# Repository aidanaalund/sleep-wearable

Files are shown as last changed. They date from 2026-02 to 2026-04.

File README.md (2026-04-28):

# UT Austin ECE Senior Design Project: Sleep Monitoring Headband

## Description

This repository contains work on our sleep state tracker wearable headband for ECE Senior Design at UT Austin. Members are Aidan Aalund, Justin Banh, Alex Ho, and Kien Ton. Mentored by Dr. Edison Thomaz. The wearable is powered by a Nordic nRF54L15 module and uses an ADS1299 biosensing amplifier from Texas Instruments for the analog front end. Bluetooth low energy transmits EEG and motion features collected by the board to a mobile app, which runs a random forest model to identify the user's current sleep stage. The app shows trends over time, ratings of sleep quality, and gives tips for improvements.

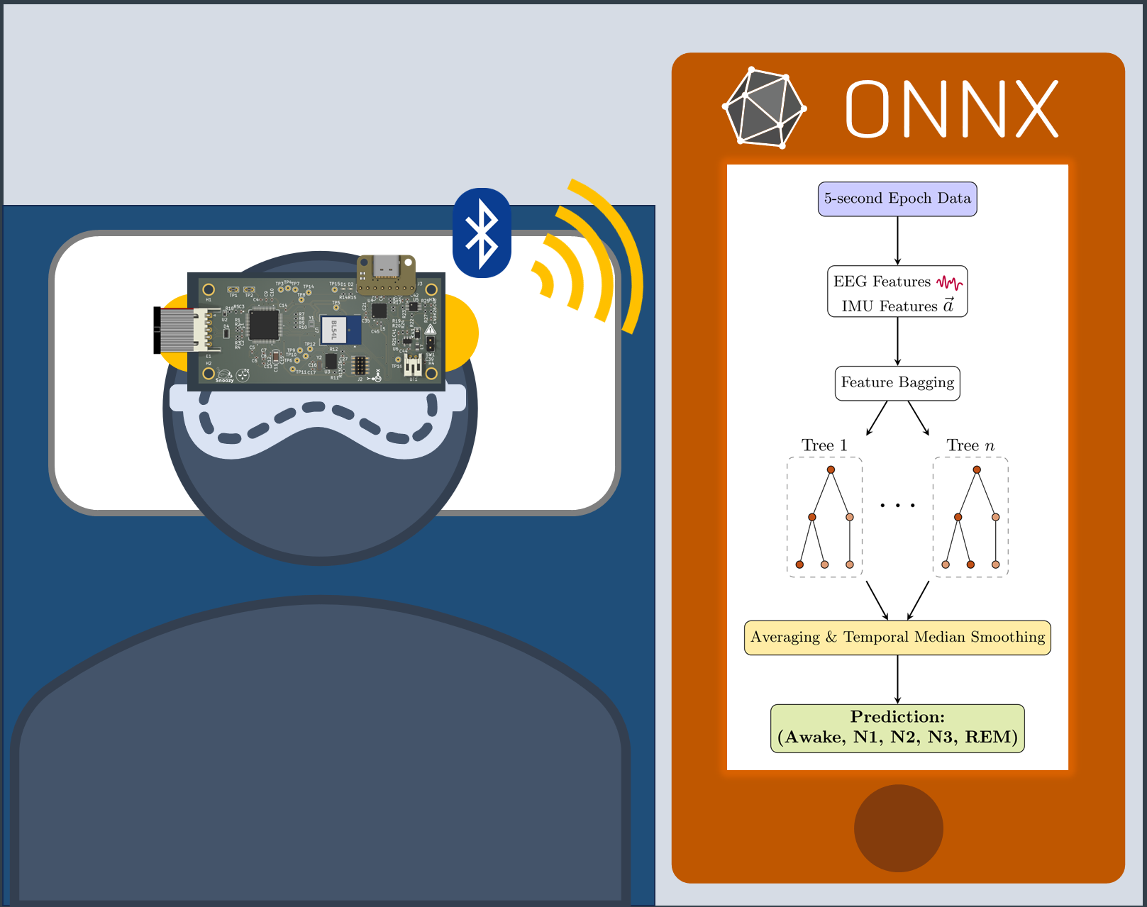
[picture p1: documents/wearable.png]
3D model of hardware showing a PCB and battery.

To view the full PCB layout online, [go to KiCanvas!](https://kicanvas.org/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)

## Repository Structure (WIP)

### Wearable device files (`./wearable`)

#### Hardware Files (`./wearable/hw`)

#### Software Files (`./wearable/sw`)

### Companion application files (`./reactNative`)

### Machine learning files (`./ml`)

#### Sleep Stage Classifier (`./ml/sleep`)

#### Meditation Classifier (`./ml/meditation`)

### Other documentation (`./documents`)

## Known Errata

- SWCLK and SWDIO labels are connected to the SWD header incorrectly in the schematic and layout

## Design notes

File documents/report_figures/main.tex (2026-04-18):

\documentclass[tikz, border=10pt]{standalone}
\usepackage[dvipsnames]{xcolor}
\usepackage{pgfplots}
\pgfplotsset{compat=1.18}
\usetikzlibrary{calc,positioning,arrows.meta}

\tikzset{
  black arrow/.style={-stealth, thick},
  node box/.style={draw=black, fill=white, text=black, rectangle, rounded corners, font=\small, align=center, minimum height=2em},
  % FIXED: Manual path for stability. No sin/cos calculations to crash the engine.
  eeg wave/.pic={
    \draw[purple, thick, x=0.05cm, y=0.15cm] 
      (0,0) -- (1,1) -- (2,-1) -- (3,1.5) -- (4,-1.2) -- (5,0.8) -- 
      (6,-0.5) -- (7,1.2) -- (8,-1.5) -- (9,0.5) -- (10,0);
  }
}

\begin{document}
\begin{tikzpicture}[font=\sffamily]

  % --- ROOT DATA INPUT ---
  \node[node box, fill=blue!20] (root) {5-second Epoch Data};

  % --- EEG BRANCH ---
  \node[node box, below=1cm of root] (eeg_input) {
    EEG Features \tikz[baseline=-0.5ex]{\pic {eeg wave}}\\
    IMU Features \large $\vec{a}$
  };
  
  \node[node box, below=1cm of eeg_input] (eeg_bagging) {Feature Bagging};
  
  % EEG Forest Representative Trees (placed as images)
  \node[inner sep=0pt] at ($(eeg_bagging)+(-1.5cm,-2.5cm)$) (et1) {};
  \node[inner sep=0pt] at ($(eeg_bagging)+(1.5cm,-2.5cm)$) (etn) {};

  \node[node box, below=4.5cm of eeg_bagging, fill=Goldenrod!50] (eeg_avg) {Averaging \& Temporal Median Smoothing};
  \node[node box, fill=SpringGreen!50, below=1cm of eeg_avg, font=\bfseries] (eeg_pred) {Prediction:\\(Awake, N1, N2, N3, REM)};

  % --- OVERRIDE LOGIC ---
  % \node[node box, fill=Goldenrod!50, below=1cm of eeg_pred.south, minimum width=4cm] (logic) {
  %   Override Logic:\\
  %   \textbf{IF} EEG = N1 \textbf{AND} IMU = Awake\\
  %   \textbf{THEN} Final = Awake
  % };

  % --- CONNECTIONS ---
  \draw[black arrow] (root) -- (eeg_input);
  
  \draw[black arrow] (eeg_input) -- (eeg_bagging);
  \draw[black arrow] (eeg_bagging) -- (et1);
  \draw[black arrow] (eeg_bagging) -- (etn);
  \draw[black arrow] (et1) -- (eeg_avg);
  \draw[black arrow] (etn) -- (eeg_avg);
  \draw[black arrow] (eeg_avg) -- (eeg_pred);

  % Ellipsis for forests
  \path (et1) -- (etn) node [midway, scale=2] {$\dots$};
  % \path (it1) -- (itn) node [midway, scale=2] {$\dots$};

\end{tikzpicture}
\end{document}

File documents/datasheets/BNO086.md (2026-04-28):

# BNO08X (BNO085/BNO086) Datasheet — Driver Reference

> Condensed from CEVA BNO08X Datasheet Revision 1.17 (2023). Optimized for writing
> Zephyr RTOS drivers. Detailed electrical/AC timing curves and packaging info have
> been summarized; protocol, report, and command details are preserved in full.

## 1. Overview

The BNO08X is a System in Package (SiP) integrating:

- Triaxial 12-bit accelerometer, range ±8g
- Triaxial 16-bit gyroscope, range ±2000°/s
- Triaxial geomagnetic sensor (magnetometer)
- 32-bit ARM Cortex-M0+ microcontroller running CEVA's SH-2 firmware (with MotionEngine)
- 28-pin LGA package, 3.8 × 5.2 × 1.1 mm

Sensors are from Bosch Sensortec; the MCU is by Atmel. The BNO086 is a drop-in
replacement for the BNO085 (identical pinout and software feature set), and adds
14-bit accelerometer fusion, lower idle power, and Interactive Calibration.

The chip provides processed motion outputs (orientation quaternions, linear accel,
gravity, calibrated gyro/mag, etc.), classification features (step counter, tap,
stability, shake, significant motion, activity), and supports environmental sensors
on a secondary I²C bus.

Host communication interfaces: **I²C, UART (SHTP), SPI, UART-RVC**, plus a bootloader
for DFU.

---

## 2. Pinout (28-pin LGA)

| Pin | Name | Mode | Description |
|-----|---|---|---|
| 1 | RESV_NC | NC | Reserved, no connect |
| 2 | GND | Input | Ground |
| 3 | VDD | Input | Sensor supply (2.4 V – 3.6 V) |
| 4 | BOOTN | Input | Bootloader mode select (low at reset → bootloader) |
| 5 | PS1 | Input | Protocol select pin 1 |
| 6 | PS0/WAKE | Input | Protocol select pin 0; doubles as SPI WAKE after reset |
| 7 | RESV_NC | Input | Reserved, no connect |
| 8 | RESV_NC | NC | Reserved, no connect |
| 9 | CAP | — | External 100 nF cap to GND |
| 10 | CLKSEL0 | Input | Clock source selection (internal pulldown) |
| 11 | NRST | Input | Active-low reset |
| 12 | RESV_NC | NC | Reserved, no connect |
| 13 | RESV_NC | NC | Reserved, no connect |
| 14 | H_INTN | Output | Active-low interrupt to host |
| 15 | ENV_SCL | Bidir | Environmental sensor I²C clock |
| 16 | ENV_SDA | Bidir | Environmental sensor I²C data |
| 17 | SA0 / H_MOSI | Input | I²C address LSB / SPI MOSI |
| 18 | H_CSN | Input | SPI chip select, active low |
| 19 | H_SCL / SCK / RX | Bidir | I²C clock / SPI clock / UART RX |
| 20 | H_SDA / H_MISO / TX | Bidir | I²C data / SPI MISO / UART TX |
| 21–24 | RESV_NC | NC | Reserved, no connect |
| 25 | GND | Input | Ground |
| 26 | XOUT32 / CLKSEL1 | Output | 32 kHz crystal output / clock-source select (pulldown) |
| 27 | XIN32 | Input | 32 kHz crystal input / external clock |
| 28 | VDDIO | Input | Core/IO supply (1.65 V – 3.6 V) |

### 2.1 Clock Source Selection

| Source | CLKSEL0 | CLKSEL1 |
|---|---|---|
| Crystal (32.768 kHz, 50 ppm, 12.5 pF) | 0 / NC | Tied to crystal |
| External clock (50 ppm) | 1 | 1 |
| Internal | 1 | 0 / NC |

> **Important:** the internal clock is **not accurate enough** for UART-SHTP or
> UART-RVC. Use external clock or crystal for UART modes.

---

## 3. Protocol Selection

The PS1/PS0 pins (sampled at reset) and BOOTN pin choose the host interface:

| PS1 | PS0 | BNO08X (BOOTN=1) | Bootloader (BOOTN=0) |
|-----|-----|---|---|
| 0 | 0 | I²C | I²C |
| 0 | 1 | UART-RVC | Reserved |
| 1 | 0 | UART-SHTP | UART |
| 1 | 1 | SPI | SPI |

In **SPI mode**, PS0 is repurposed as the WAKE signal *after* reset.

---

## 4. Host Interfaces

### 4.1 I²C

- Standard Fast-mode, up to **400 kbps**
- 7-bit slave address: `0b1001010X` where X = SA0 pin
  - SA0 = 0 → `0x4A`; SA0 = 1 → `0x4B`
- Bootloader I²C address: `0x28` or `0x29` (SA0 LSB)
- Master MUST support **clock stretching**
- Multi-byte data is **little-endian**, byte transfers are MSB-first
- Repeated-start register-style accesses are **not** supported by the application
  (uses SHTP framing, see §5)
- BNO085 polling with no data → device stretches clock until data is available
- BNO086 polling with no data → device returns zero-length packet; host should
  read the length field and **ignore zero-length packets**

#### Connection guidelines
- `H_INTN` (active low) → GPIO with wake capability
- `BOOTN` → 10 kΩ pull-up; tie to GPIO if DFU is needed
- `PS1`, `PS0` → both tied to GND for I²C
- `H_SCL`/`H_SDA` need pull-ups (~2–4 kΩ depending on bus capacitance)
- Secondary `ENV_SCL`/`ENV_SDA` lines must be pulled up regardless of presence of
  environmental sensors (firmware probes them at reset)

### 4.2 UART-SHTP

- 3 Mbps, 8N1, no parity, idle high
- LSB first
- Bytes from host → BNO must be separated by **≥ 100 µs**
- Bytes from BNO → host have no extra spacing
- `H_INTN` is asserted low ~7.7 µs before the first byte of a transmission and
  deasserts before the last byte; used for host-side timestamping
- Requires external clock or crystal
- Pin tying: PS1 = VDDIO, PS0 = GND
- Uses SHTP framing (see §5) with start/end framing bytes

### 4.3 SPI

- 4-wire, mode 3 (CPOL = 1, CPHA = 1; clock idles high, sampled on rising edge)
- Up to 3 MHz
- MSB first, 8-bit byte oriented
- BNO08X is always slave
- `H_INTN` indicates the BNO has data ready or has woken up
- Pin tying: PS1 = VDDIO, PS0 = GPIO (used as WAKE *after* reset)

#### Wake operation
1. Host drives PS0/WAKE low
2. BNO asserts `H_INTN` low
3. Host asserts `H_CSN` and reads/writes
4. BNO deasserts `H_INTN` once `H_CSN` is observed

#### Responding to H_INTN
If the host fails to respond to `H_INTN` within ~10 ms, the BNO times out,
deasserts `H_INTN`, and retries. Repeated delays cause processing starvation
and degraded outputs. **Target: handle `H_INTN` within 1/10 of the fastest
configured sensor period.**

### 4.4 UART-RVC

- 115200 bps, 8N1, no parity, idle high
- One-way, 100 Hz, fixed 19-byte packets transmitted by BNO
- Requires external clock or crystal
- Pin tying: PS1 = GND, PS0 = VDDIO

#### RVC Packet Format (19 bytes)

| Offset | Field | Notes |
|---|---|---|
| 0–1 | Header | `0xAA 0xAA` |
| 2 | Index | Monotonic 8-bit counter |
| 3–4 | Yaw | int16 LE, 0.01° units, ±180° around Z |
| 5–6 | Pitch | int16 LE, 0.01° units, ±90° around Y |
| 7–8 | Roll | int16 LE, 0.01° units, ±180° around X |
| 9–10 | X accel | int16 LE, mg |
| 11–12 | Y accel | int16 LE, mg |
| 13–14 | Z accel | int16 LE, mg |
| 15 | MI | BNO086: Motion Intent. Otherwise reserved |
| 16 | MR | BNO086: Motion Request. Otherwise reserved |
| 17 | Reserved | One byte (BNO086) or three (otherwise), zero |
| 18 | Csum | Sum of bytes 2–17 (Index, yaw, pitch, roll, accel, reserved) |

Apply rotations in order **yaw → pitch → roll** to recover orientation.

Example (from datasheet):
`AA AA DE 01 00 92 FF 25 08 8D FE EC FF D1 03 00 00 00 E7`
- Index = 0xDE = 222
- Yaw = 0x0001 → 0.01°
- Pitch = 0xFF92 → −1.10°
- Roll = 0x0825 → 20.85°
- X = 0xFE8D → −371 mg
- Y = 0xFFEC → −20 mg
- Z = 0x03D1 → 977 mg
- Csum = 0xE7

#### RVC startup banner
On reset, the BNO transmits an ASCII banner, e.g.:
```
%Hillcrest Labs 10003608
%SW Ver 3.2.x
%(c) 2017 Hillcrest Laboratories, Inc.
```
Then 100 Hz packets stream continuously.

---

## 5. SHTP (Sensor Hub Transport Protocol)

Used by I²C, UART-SHTP, and SPI. Every transfer begins with a 4-byte header:

| Byte | Field |
|---|---|
| 0 | Length LSB |
| 1 | Length MSB (bit 15 = continuation flag) |
| 2 | Channel |
| 3 | SeqNum |

- **Length:** total bytes including header. Bit 15 of MSB byte = continuation
  flag (host shouldn't send fragmented messages to the BNO; the BNO can send
  them). Length `0xFFFF` is reserved (failure marker). Max cargo = 32766 − 4.
- **Channel:** SHTP channel number (see below)
- **SeqNum:** monotonic per-channel-per-direction counter (used to detect drops
  and pair fragments)

The length field allows hosts to schedule the right number of clocks for I²C/SPI
reads. Partial reads are supported — read 4 bytes to get the length, then re-read
with the right size.

### 5.1 SHTP Channels

| Ch | Name | Purpose |
|----|---|---|
| 0 | Command | SHTP control |
| 1 | Executable | Reset / on / sleep commands |
| 2 | SH-2 control | Sensor hub config and responses |
| 3 | Input reports | Non-wake sensor reports (excluding gyro RV) |
| 4 | Wake input reports | Reports from sensors flagged as wake |
| 5 | Gyro RV | Gyro Rotation Vector (separate channel for low latency) |

### 5.2 Executable Channel (Channel 1)

| Direction | Value | Meaning |
|---|---|---|
| Host → BNO | 0 | Reserved |
| Host → BNO | 1 | Reset |
| Host → BNO | 2 | On (re-enable all sensors) |
| Host → BNO | 3 | Sleep (only wake/always-on sensors keep running) |
| BNO → Host | 1 | Reset complete |

### 5.3 Reset Sequence

After power-on or NRST:
1. BNO asserts `H_INTN` when ready
2. Host reads the **SHTP advertisement packet** (channel maps, packet length info)
3. Executable channel sends a reset message
4. SH-2 sends an unsolicited initialization message on channel 2
5. BNO waits for host configuration

Startup timing (typ): NRST pulse ≥ 10 ns, internal init ≈ 90 ms, internal
config ≈ 4 ms before `H_INTN` first asserts.

---

## 6. SH-2 Report IDs (Channel 2 — Sensor Hub Control)

All commands/responses on channel 2 begin with a Report ID (after the SHTP header):

| Report ID | Direction | Description |
|---|---|---|
| 0xFE | Host → BNO | Get Feature Request |
| 0xFD | Host → BNO | Set Feature Command |
| 0xFC | BNO → Host | Get Feature Response |
| 0xF9 | Host → BNO | Product ID Request |
| 0xF8 | BNO → Host | Product ID Response |
| 0xF7 | Host → BNO | FRS Write Request |
| 0xF6 | Host → BNO | FRS Write Data |
| 0xF5 | BNO → Host | FRS Write Response |
| 0xF4 | Host → BNO | FRS Read Request |
| 0xF3 | BNO → Host | FRS Read Response |
| 0xF2 | Host → BNO | Command Request |
| 0xF1 | BNO → Host | Command Response |
| 0xFB | BNO → Host | Timebase Reference (precedes input reports) |

### 6.1 Product ID Request (0xF9)

| Byte | Field |
|---|---|
| 0 | Report ID = 0xF9 |
| 1 | Reserved |

### 6.2 Product ID Response (0xF8)

| Byte | Field |
|---|---|
| 0 | Report ID = 0xF8 |
| 1 | Reset Cause |
| 2 | SW Version Major |
| 3 | SW Version Minor |
| 4–7 | SW Part Number (LE) |
| 8–11 | SW Build Number (LE) |
| 12–13 | SW Version Patch (LE) |
| 14–15 | Reserved |

### 6.3 Set Feature Command (0xFD)

| Byte | Field |
|---|---|
| 0 | Report ID = 0xFD |
| 1 | Feature Report ID (the sensor to configure) |
| 2 | Feature flags (bit 1 = wake; see [1]) |
| 3–4 | Change sensitivity (signed, abs/rel selected by flags) |
| 5–8 | Report Interval (µs, LE) |
| 9–12 | Batch Interval (µs, LE) |
| 13–16 | Sensor-specific configuration word (LE) |

Sensors can be configured for:
- **Periodic reporting** (Report Interval)
- **Change-only reporting** (Change Sensitivity, absolute or relative threshold)
- **Batching** (Batch Interval — accumulate before pushing to host; supports
  power-saving by letting host sleep)

A sensor flagged as a wake sensor cannot also be a non-wake (always-on) sensor —
each sensor type has only one batch queue.

The BNO emits a **Get Feature Response** (0xFC) immediately after a Set Feature
and again whenever the operating rate changes.

### 6.4 Effective Sample Rate

The BNO will satisfy:

```
0.9 × RequestedRate ≤ ConfiguredRate ≤ 2.1 × RequestedRate
```

depending on underlying sensor capabilities.

---

## 7. Sensor Input Reports

Each sensor has a dedicated Report ID for its input report (delivered on channel
3, 4, or 5). All input reports share the same general layout: report ID, sequence
number, status, delay, then the payload.

### 7.1 Common Input Report Header

| Byte | Field |
|---|---|
| 0 | Report ID (sensor specific) |
| 1 | Sequence number (monotonic; gaps = dropped samples) |
| 2 | Status: bits[1:0] = accuracy; bits[7:2] = delay upper 6 bits |
| 3 | Delay: lower 8 bits of delay (resolution: 100 µs) |
| 4..N | Sensor data |

Accuracy values:

| Bits[1:0] | Meaning |
|---|---|
| 0 | Unreliable |
| 1 | Low |
| 2 | Medium |
| 3 | High |

### 7.2 Calibrated Gyroscope Report (Report ID 0x02)

| Byte | Field |
|---|---|
| 0 | 0x02 |
| 1 | Seq |
| 2 | Status |
| 3 | Delay |
| 4–5 | X (int16 LE, rad/s with Q-point per metadata) |
| 6–7 | Y |
| 8–9 | Z |

(Other sensors use the same template with different report IDs and payload.
Refer to SH-2 Reference Manual [1] for the full list.)

### 7.3 Timebase Reference Report (0xFB)

Often prepended to a batch of sensor reports:

| Byte | Field |
|---|---|
| 0 | 0xFB |
| 1–4 | Base Delta (signed, LE, units of 100 µs) |

To timestamp a sample:

```
sample_time = host_intn_timestamp − base_delta − sensor_report_delay
```

When a Timebase Reference precedes a report, the report's own delay is usually
zero, but if reports are concatenated due to processing delay, the report's
delay field will also be populated and must be added on top of the base delta.

Example: timebase delta = 120 (12 ms), report 1 delay = 0, report 2 delay = 17:
- Report 1 timestamp = T − 12 ms
- Report 2 timestamp = T − 12 ms + 1.7 ms = T − 10.3 ms

---

## 8. FRS (Flash Record System)

Persistent configuration is stored in flash records. Records are read/written via
the FRS Read/Write request/response sequence on channel 2.

### 8.1 FRS Records

| Record ID | Description |
|---|---|
| 0x7979 | Static calibration – AGM |
| 0x4D4D | Nominal calibration – AGM |
| 0x8A8A | Static calibration – SRA |
| 0x4E4E | Nominal calibration – SRA |
| 0x1F1F | Dynamic calibration |
| 0xD3E2 | MotionEngine power management |
| 0x2D3E | System orientation |
| 0x2D41 | Primary accelerometer orientation |
| 0x2D46 | Gyroscope orientation |
| 0x2D4C | Magnetometer orientation |
| 0x3E2D | AR/VR stabilization – Rotation Vector |
| 0x3E2E | AR/VR stabilization – Game Rotation Vector |
| 0xC274 | Significant Motion detector configuration |
| 0x7D7D | Shake detector configuration |
| 0xD7D7 | Maximum fusion period |
| 0x4B4B | Serial number |
| 0x39AF | Pressure calibration |
| 0x4D20 | Temperature calibration |
| 0x1AC9 | Humidity calibration |
| 0x39B1 | Ambient light calibration |
| 0x4DA2 | Proximity calibration |
| 0xD401 | ALS calibration |
| 0xD402 | Proximity sensor calibration |
| 0xED85 | Stability detector configuration |
| 0x74B4 | User record |
| 0xD403 | MotionEngine Time Source Selection |
| 0xA1A2 | Gyro-Integrated Rotation Vector configuration |

### 8.2 FRS Write Sequence
1. Host → BNO: FRS Write Request (record ID, length)
2. BNO → Host: FRS Write Response (ack)
3. Host → BNO: FRS Write Data (repeated)
4. BNO → Host: Final FRS Write Response (success or failure)

### 8.3 FRS Read Sequence
1. Host → BNO: FRS Read Request (record ID)
2. BNO → Host: FRS Read Response (data, repeated until completion marker)

### 8.4 Sensor Metadata

Sensor metadata is also stored as FRS records. Each metadata record contains:

- Version (LSB = ME, byte 1 = MH, byte 2 = SH)
- Range (unsigned fixed-point, units & Q-point match input report)
- Resolution (same format)
- Power (mA, Q-point 10)
- Revision
- Min period (µs)
- FIFO max count, FIFO reserved count, batch buffer bytes
- Vendor ID length
- Q points 1, 2, 3 (signed 16-bit) for data, bias/accuracy, change sensitivity
- Sensor-specific metadata length (must be multiple of 4)
- Max period (µs)
- Sensor-specific metadata
- Vendor ID string (null-terminated)

---

## 9. Available Motion Outputs

### 9.1 Acceleration
- **Calibrated Acceleration** (m/s², includes gravity)
- **Linear Acceleration** (m/s², gravity removed; requires gyro fusion)
- **Gravity** (m/s²)
- **Raw Accelerometer** (ADC units; requires accelerometer to be enabled separately)

### 9.2 Angular Velocity
- **Calibrated Gyroscope** (rad/s)
- **Uncalibrated Gyroscope** (rad/s, with bias as second output; for Android compat)
- **Raw Gyroscope** (ADC units; requires gyroscope enabled separately)

### 9.3 Magnetometer
- **Magnetic Field Calibrated** (µT)
- **Magnetic Field Uncalibrated** (µT, with hard-iron offset as second output)
- **Raw Magnetic Field** (ADC units)

### 9.4 Orientation (Quaternions)

| Output | Sensors used | Notes |
|---|---|---|
| Geomagnetic Rotation Vector | Accel + Mag | Lower power, less responsive, mag-error sensitive |
| Game Rotation Vector | Accel + Gyro | No magnetic reference; yaw drifts long-term |
| AR/VR Stabilized Game Rotation Vector | Accel + Gyro | Reduces sudden corrections; tunable via FRS |
| Rotation Vector | Accel + Gyro + Mag | Most accurate; references magnetic north |
| AR/VR Stabilized Rotation Vector | All three | Smoothed corrections for AR/VR |
| Gyro Rotation Vector | Optimized | Up to 1 kHz, low latency for HMDs |
| Gyro Rotation Vector Prediction | Predicted | Forecasts ~20–30 ms ahead |

### 9.5 Maximum Sensor Rates

| Sensor | Max rate (Hz) |
|---|---|
| Gyro Rotation Vector | 1000 |
| Rotation Vector | 400 |
| Game Rotation Vector | 400 |
| Geomagnetic Rotation Vector | 90 |
| Gravity | 400 |
| Linear Acceleration | 400 |
| Accelerometer | 500 |
| Gyroscope | 400 |
| Magnetometer | 100 |

Sensors cannot all run at maximum simultaneously — bandwidth and processing time
must be balanced.

### 9.6 Typical Latency

| Sensor | @100 Hz | @200 Hz |
|---|---|---|
| Gyro Rotation Vector | 6.6 ms | 3.7 ms |
| Rotation Vector | 6.6 ms | 3.7 ms |
| Game Rotation Vector | 6.6 ms | 3.7 ms |

---

## 10. Classification / Always-On Features

### 10.1 Stability Detector & Classifier
- **Detector** uses accel only (lower power); reports stable/motion based on
  acceleration threshold (default 0.784 m/s²) over a time threshold (default 500 ms)
- **Classifier** uses accel + gyro; reports On Table / Stable / Motion. Default
  thresholds: 1 rad/s, 3 s. Configured via FRS 0xD3E2 (MotionEngine power /
  stability classifier) and 0xED85 (stability detector).

### 10.2 Tap Detector
- Uses accelerometer; reports single or double tap and the axis it occurred on
- Axes match the Android frame of reference

### 10.3 Step Detector / Counter
- **Step Detector** outputs 1.0 per step. Configurable: `watchSelector` (1 for
  wrist worn), `allowTime` (default 250 ms), `stepMinTime` (default 300 ms),
  `groupDelay` (90 ms — don't change without consultation), `threshold`
  (3.1 mm), `thresholdWatch` (0.01), `thresholdNonWatch` (1.2e-4)
- **Step Counter** is a 16-bit counter built on the detector with reclassification
  for accuracy. Host must accumulate 64-bit total across rollovers; the BNO will
  wake the host before overflow.

### 10.4 Activity Classifier
- Uses accel (and optionally an external pressure sensor for stair detection)
- Classes: Still / Walking / Running / On Stairs / In-Vehicle / On-Bicycle / Tilting
- Defaults: walk step rate 0.75–2.25/s, run lower 1.25/s; signal-strength
  thresholds: walk 0.75–4.50 m²/s², run 3.20–23.50 m/s²
- 4 s analysis window

### 10.5 Significant Motion Detector
- Auto-disables after firing (per Android spec)
- Defaults: 5-step threshold, 10 m/s² acceleration threshold
- Configured via FRS 0xC274

### 10.6 Shake Detector
- Defaults: 8 m/s² magnitude, 3 direction changes, 50–400 ms between changes,
  all axes
- Configured via FRS 0x7D7D

---

## 11. Coordinate System & Orientation

The BNO uses the Android frame of reference:
- X: horizontal, right = positive
- Y: vertical, up = positive
- Z: out of the front face = positive
- Counter-clockwise rotations are positive

### 11.1 Mounting Orientation (FRS 0x2D3E)

The system orientation FRS record is a unit quaternion `(qw, qx, qy, qz)`
applied to all sensor outputs. Each component is signed Q30 fixed-point (32-bit).

Example mappings (BNO-axis → device-axis when device frame is East/North/Up):

| BNO X | BNO Y | BNO Z | Qw | Qx | Qy | Qz |
|---|---|---|----|----|----|----|
| East | North | Up | 1 | 0 | 0 | 0 |
| North | West | Up | √2/2 | 0 | 0 | √2/2 |
| West | South | Up | 0 | 0 | 0 | 1 |
| South | East | Up | √2/2 | 0 | 0 | −√2/2 |
| East | South | Down | 0 | 0 | −1 | 0 |
| North | East | Down | 0 | −√2/2 | −√2/2 | 0 |
| West | North | Down | 0 | −1 | 0 | 0 |
| South | West | Down | 0 | −√2/2 | √2/2 | 0 |

(Datasheet has full 24-row table for all axis-aligned orientations.)

### 11.2 Tare

Two flavours:
- **Tare around all axes** — solves tilt + heading
- **Tare around Z** — solves heading only

After tare, call **Persist Tare** to save across resets. Note: persist-tare does
not apply to the Game Rotation Vector — for that, the BNO must be reset to apply
tare-Z.

For Rotation Vector / Geomagnetic Rotation Vector, magnetic north must be
resolved before taring (otherwise calibration will shift the heading later).

See the BNO08X Tare Function Usage Guide [8].

---

## 12. Calibration

### 12.1 Categories

- **Static calibration** — non-varying offsets, scaling, skew, sensor orientation
  relative to device. Stored in the SCD record.
- **Dynamic calibration** — runs on-chip continuously; corrects offsets that
  vary over time/temperature (gyro ZRO, accel ZGO, magnetometer hard/soft iron).

### 12.2 Calibration Command

Use the Command Request (0xF2) to enable/disable dynamic calibration per sensor.
Settings **do not persist** across reset. See SH-2 Reference Manual [1] for the
exact subcommand layout.

### 12.3 Calibration Procedure

| Sensor | Procedure |
|---|---|
| Accelerometer (3D) | Hold device in 4–6 unique orientations, ~1 s each |
| Accelerometer (planar) | Rotate around Z-axis ≥ 180° (RVC apps) |
| Gyroscope | Place stationary on a stable surface for 2–3 s |
| Magnetometer | Rotate ~180° and back on each of roll/pitch/yaw, ~2 s each |

Defaults: accel and mag calibration enabled in all modes except UART-RVC.
UART-RVC enables planar-ZGO accel calibration by default.

For VR/AR head tracking, prefer Game Rotation Vector or Gyro Rotation Vector and
disable mag calibration to avoid heading jumps.

### 12.4 Persisting Dynamic Calibration

DCD is auto-saved to RAM every 5 s. On non-power-up reset, the last RAM copy is
written to FRS. Use the **Clear-DCD and Reset** command [1] to wipe before reset.

For SHTP applications: explicit **Save DCD** request and **Configure Periodic
DCD Save** command are also available.

### 12.5 Interactive Calibration (BNO086 only)

For applications where low heading drift is critical, the BNO086 supports a
cooperative calibration mode where the host application coordinates ZRO updates.
See SH-2 Reference Manual.

---

## 13. Environmental Sensors

Supported on the secondary I²C bus (`ENV_SCL`/`ENV_SDA`):

- Bosch BME280 (pressure / humidity / temperature)
- Bosch BMP280 (pressure / temperature) — populate either BME280 or BMP280, not both
- Capella CM36686 (proximity / ALS)

The BNO probes this bus at reset, so pull-ups are required even if no env
sensors are present. ALS/proximity typically need calibration when mounted
behind glass/plastic.

---

## 14. Bootloader / DFU

- Entered when `BOOTN` is low at reset/power-on
- Uses the same interface as selected by PS1/PS0 (I²C/SPI/UART; UART-RVC reserved)
- I²C bootloader address: `0x28` or `0x29` (SA0)
- Workflow: host sends application size, then frames; BNO reports per-frame
  status; host verifies and exits bootloader by deasserting BOOTN and resetting.
- Reference DFU host code is available from CEVA on request.

---

## 15. Electrical & Timing (Summary)

> Detailed AC curves are omitted — see the full datasheet for production-grade
> values. The numbers below are sufficient for driver bring-up.

### 15.1 Power
- VDD: 2.4–3.6 V (sensor supply)
- VDDIO: 1.65–3.6 V (core/IO)
- **VDD must come up before or at the same time as VDDIO**
- Operating temp: −40 °C to +85 °C

### 15.2 Logic Levels
- VIH: 0.7 × VDDIO (≤2.7 V) or 0.55 × VDDIO (>2.7 V)
- VIL: 0.25 × VDDIO (≤2.7 V) or 0.30 × VDDIO (>2.7 V)
- VOH ≥ 0.8 × VDDIO at 10 mA
- VOL ≤ 0.2 × VDDIO at 20 mA

### 15.3 Timing Highlights
- I²C: up to 400 kHz, master must support clock stretching
- SPI: up to 3 MHz, mode 3
- UART-SHTP: 3 Mbps, 8N1, ≥100 µs gap between host→BNO bytes
- UART-RVC: 115200 bps, 8N1
- Reset (NRST) pulse ≥ 10 ns
- Internal init after reset: ~90 ms before `H_INTN` first asserts
- Internal config: +4 ms typ
- SPI WAKE: ~150 µs from PS0/WAKE assertion to `H_INTN`
- I²C addr-recognized to `H_INTN` deassert: ~10 µs
- SPI `H_CSN` to `H_INTN` deassert: ~800 ns
- UART `H_INTN` assert to first TX bit: ~7.7 µs

### 15.4 Power Consumption (typical, SPI, VDDIO=3 V, VDD=3.3 V)

**BNO086 (lower power)**
| Configuration | VDDIO mA | VDD mA | Total mW |
|---|---|---|---|
| Idle | 0.047 | 0.01 | 0.17 |
| Gyro RV @ 1000 Hz | 6.84 | 7.50 | 45.27 |
| Sensor Fusion @ 100 Hz | 3.18 | 7.50 | 34.29 |
| Calibrated Gyro @ 100 Hz | 2.92 | 7.50 | 33.51 |
| Geomagnetic RV @ 100 Hz | 2.11 | 4.70 | 21.84 |
| Calibrated Accel @ 125 Hz | 0.98 | 0.15 | 3.44 |
| Significant Motion | 0.34 | 0.14 | 1.66 |
| Step Counter | 0.36 | 0.14 | 1.54 |
| Tap Detector | 0.05 | 0.15 | 0.65 |
| Stability Detector | 0.05 | 0.01 | 0.18 |

(BNO085 numbers are similar but with slightly higher idle / detector currents.)

---

## 16. Performance Characteristics (Typical)

| Output | Dynamic accuracy | Static accuracy |
|---|---|---|
| Rotation Vector | 3.5° | 2.0° |
| Game Rotation Vector | 2.5° (non-heading) + 0.5°/min heading drift | 1.5° (non-heading) |
| Geomagnetic Rotation Vector | 4.5° | 3.0° |
| Gravity | — | 1.5° |
| Linear Acceleration | 0.35 m/s² | — |
| Accelerometer | 0.3 m/s² | — |
| Gyroscope | 3.1°/s | — |
| Magnetometer | 1.4 µT | — |

Real-world rotation vector accuracy is typically ~5°; geomagnetic ~10°
(highly dependent on local magnetic environment).

---

## 17. Driver Bring-up Checklist (Zephyr-relevant)

1. **Strap pins** correctly at reset:
   - I²C: PS1=0, PS0=0
   - SPI: PS1=1, PS0=1 (PS0 then becomes WAKE)
   - UART-SHTP: PS1=1, PS0=0
   - UART-RVC: PS1=0, PS0=1
   - BOOTN = 1 for normal app, 0 for DFU
   - CLKSEL0/1 per clock source
2. **Reset and wait** for `H_INTN` low (~94 ms after NRST deasserts).
3. **Read SHTP advertisement** (channel 0 broadcast).
4. **Read reset notifications** from channel 1 (executable) and channel 2 (SH-2 init).
5. **Send Product ID Request (0xF9)** to confirm part identity and firmware version.
6. **(Optional) Configure system orientation** via FRS 0x2D3E.
7. **Enable sensors** with Set Feature (0xFD) on channel 2:
   - Pick a Report ID for the desired output
   - Set Report Interval (µs)
   - Set Batch Interval (0 = no batching)
   - Set Feature Flags (e.g., wake bit if needed)
8. **Service `H_INTN`** within 1/10 of the fastest sensor period; read reports
   from channels 3 / 4 / 5 depending on configuration.
9. **Timestamp** using Timebase Reference (0xFB) + per-report delay.
10. **For SPI**: pulse PS0/WAKE low whenever the host wants to push a message
    while the BNO is idle; wait for `H_INTN` then assert CS.
11. **For BNO086 I²C polling** with no data → ignore zero-length packets.

---

## 18. Important Software References

These are the canonical CEVA documents — consult them for full register/command
detail beyond what is summarized here:

1. **1000-3625 — SH-2 Reference Manual** (full report ID and command layouts)
2. **1000-3535 — Sensor Hub Transfer Protocol** (SHTP framing, fragmentation)
3. Android Sensors HAL Overview (Google) — sensor-type definitions
4. NXP UM10204 — I²C-bus specification
5. Bosch BMF055 datasheet — underlying MEMS / package details
6. BNO055 handling, soldering & mounting instructions (Bosch)
7. **1000-4044 — BNO08X Sensor Calibration Procedure**
8. **1000-4045 — BNO08X Tare Function Usage Guide**

---

## 19. Source

Condensed from CEVA's *BNO08X Datasheet* (document 1000-3927, revision 1.17,
dated 2023-07-24). © 2023 CEVA, Inc. — see original document for legal notices.

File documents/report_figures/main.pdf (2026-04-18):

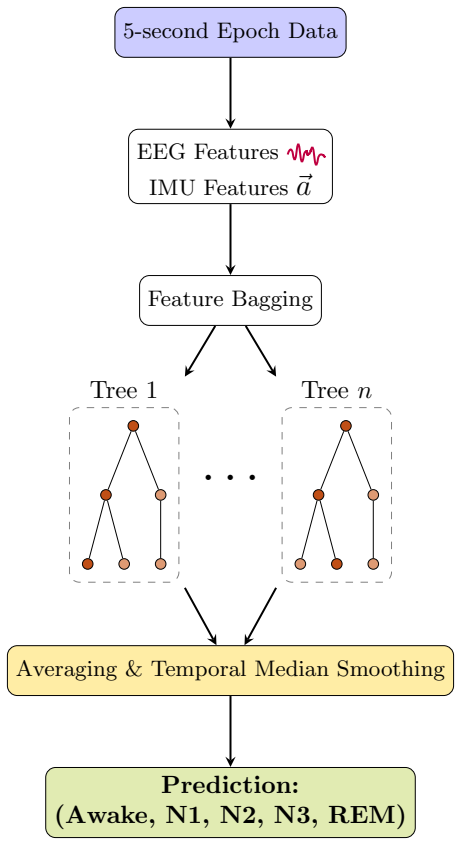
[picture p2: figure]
5-second Epoch Data; EEG Features; IMU Features ⃗a; Feature Bagging; Tree 1; Tree n; Averaging & Temporal Median Smoothing; Prediction: (Awake, N1, N2, N3, REM)

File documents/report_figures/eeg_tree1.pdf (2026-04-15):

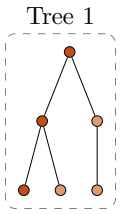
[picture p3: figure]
Tree 1

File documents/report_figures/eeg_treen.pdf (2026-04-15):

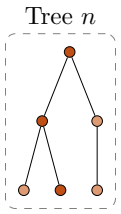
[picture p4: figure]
Tree n

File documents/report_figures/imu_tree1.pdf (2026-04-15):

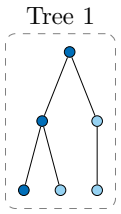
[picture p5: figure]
Tree 1

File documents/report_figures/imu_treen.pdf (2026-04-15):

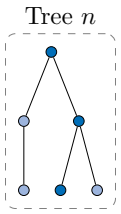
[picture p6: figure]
Tree n

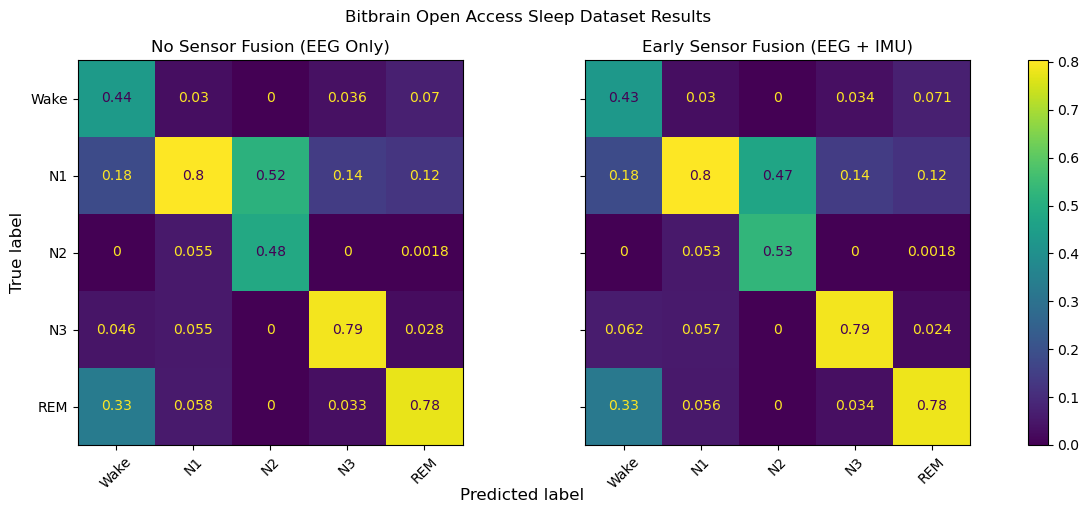
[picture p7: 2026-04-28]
documents/report_figures/output.png

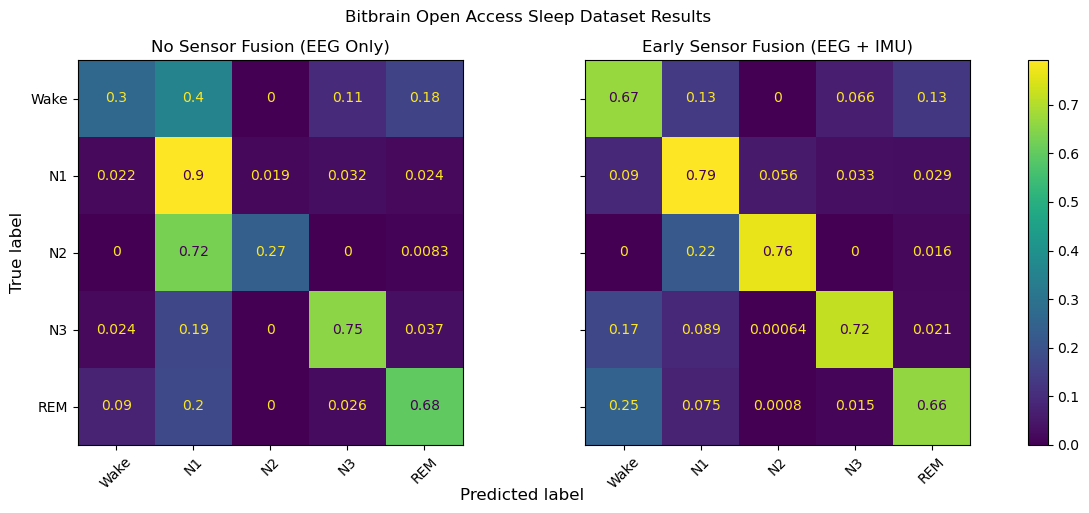
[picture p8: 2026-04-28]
documents/report_figures/output_row_normalized.png

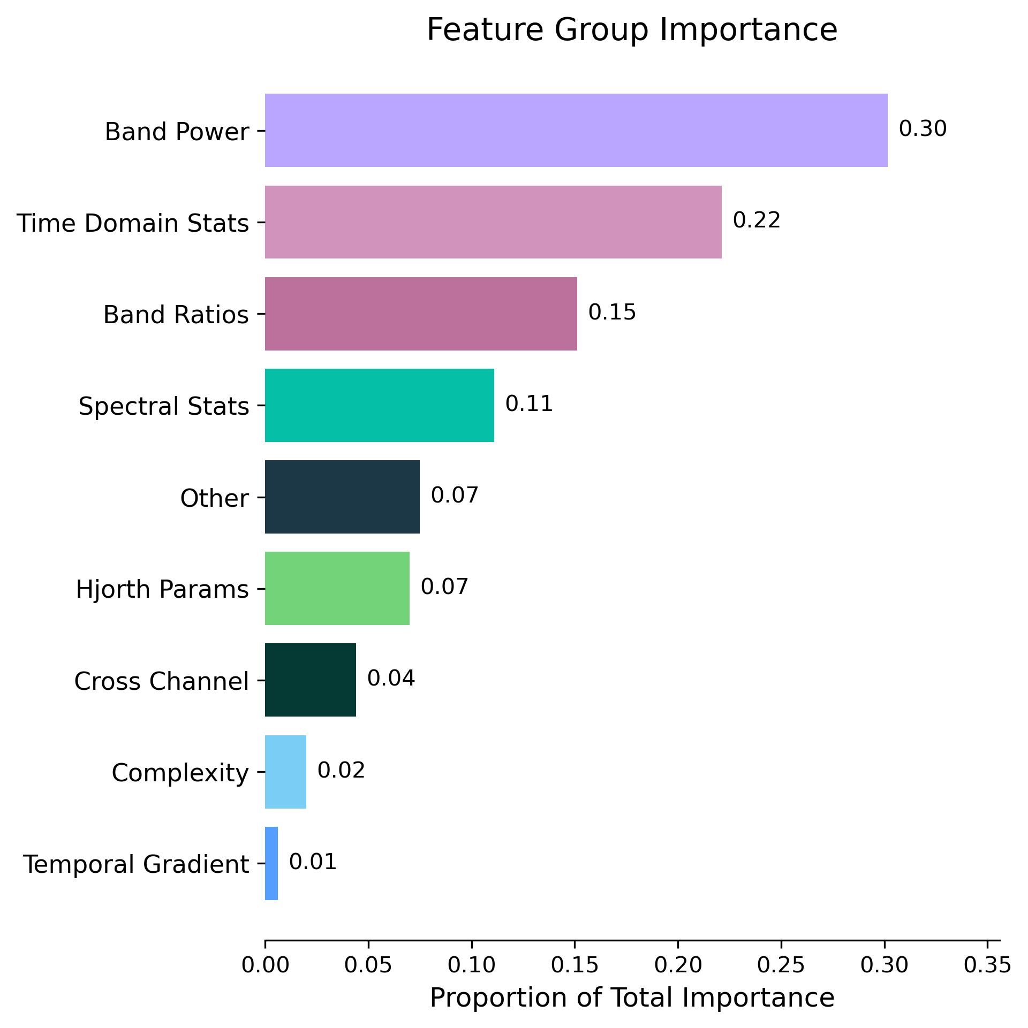
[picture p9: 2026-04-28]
documents/report_figures/02a_feature_group_importance.png

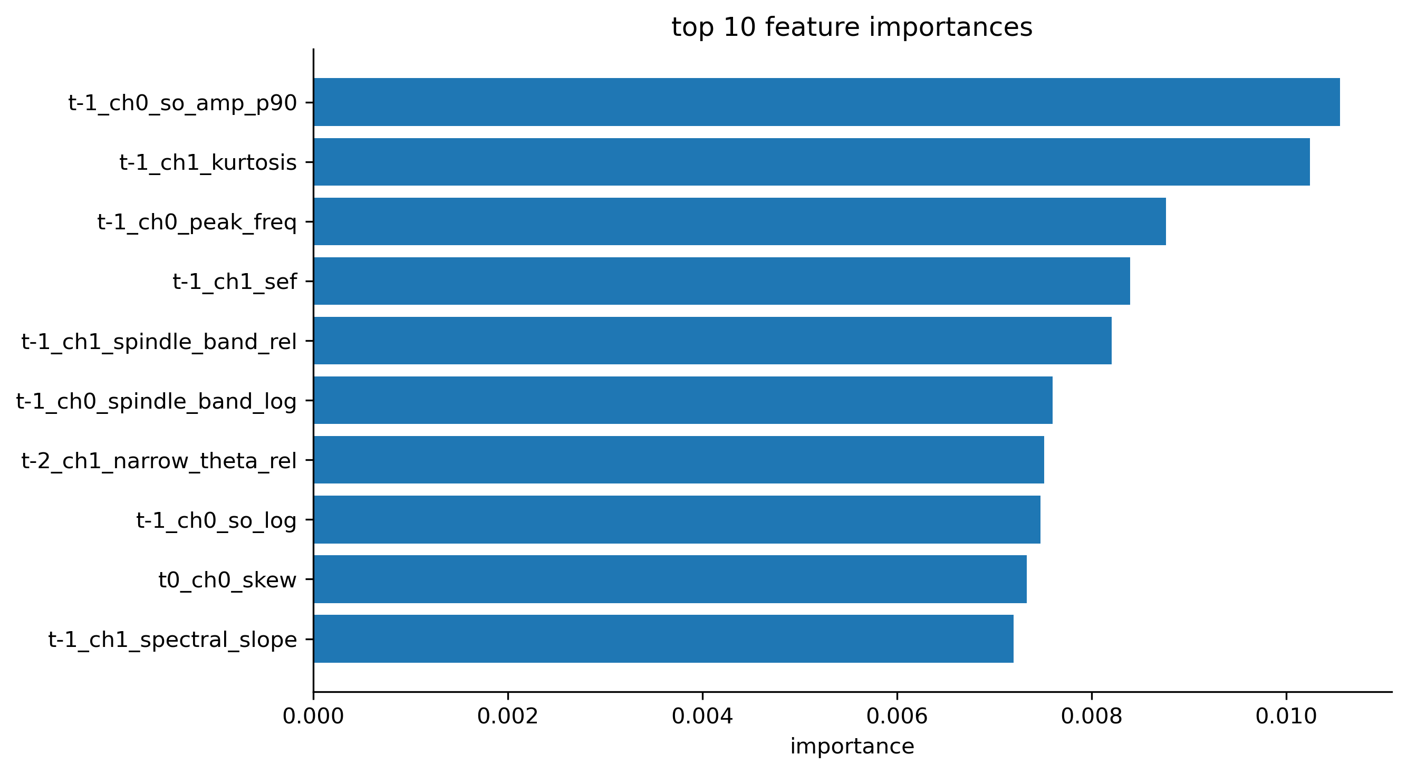
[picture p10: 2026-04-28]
documents/report_figures/02_feature_importance_top10.png

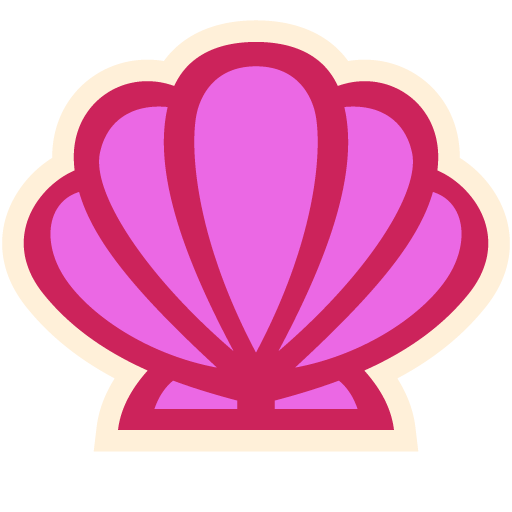
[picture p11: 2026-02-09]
wearable/hw/wearable/assets/seashell.png

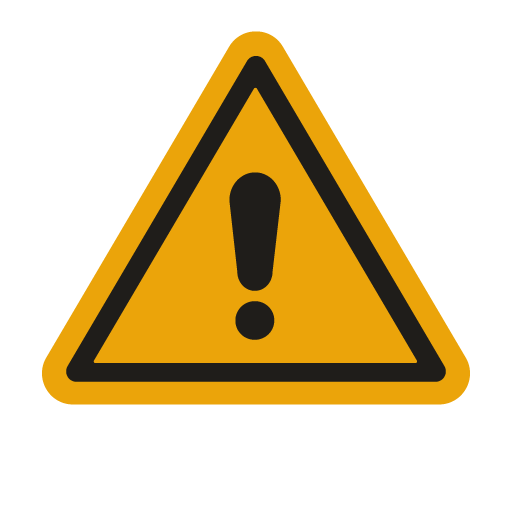
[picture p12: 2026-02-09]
wearable/hw/wearable/assets/warning.png

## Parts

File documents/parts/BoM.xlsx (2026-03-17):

Reference | Value | Footprint | Qty | mouser# | Manufacturer Name | Datasheet URL | Description | Quoted Part Number | Order Quantity | Order Price | Min\Mult Order Qty | Estimated Tariff Price
BT1 | 3.7V | Connector_JST:JST_PH_S2B-PH-K_1x02_P2.00mm_Horizontal | 1 | 306-S2BPHKSLFSNPP | JST | https://www.mouser.com/datasheet/3/1070/1/ePH.pdf | Headers & Wire Housings Headers & Wire Housings PH HEADER (SIDE) | 306-S2BPHKSLFSNPP | 1 | $0.10 | 1\1 | $0.02 | $0.02
C1,C2 | 4.7nF | Capacitor_SMD:C_0402_1005Metric | 2 | 81-GRM1555C1H472JE1D | Murata | https://www.mouser.com/datasheet/3/76/2/GRM1555C1H472JE01_01A.pdf | Multilayer Ceramic Capacitors MLCC - SMD/SMT Multilayer Ceramic Capacitors MLCC - SMD/SMT 4700 pF 50 VDC 5% 0402 C0G (NP0) | 81-GRM1555C1H472JE1D | 2 | $0.10 | 1\1 | $0.01 | $0.03
C3 | 1.5nF | Capacitor_SMD:C_0402_1005Metric | 1 | 77-VJ0402A1R5CXACBC | Vishay | https://www.vishay.com/doc?28548 | Multilayer Ceramic Capacitors MLCC - SMD/SMT Multilayer Ceramic Capacitors MLCC - SMD/SMT 0402 1.5pF 50volts C0G +/-0.25pF | 77-VJ0402A1R5CXACBC | 1 | $0.15 | 1\1 | $0.06 | $0.06
C4,C6,C10,C12,C13,C15,C21,C33 | 1uF | Capacitor_SMD:C_0402_1005Metric | 8 | 80-C1812S105K1RAUTO | KEMET | https://www.mouser.com/datasheet/3/508/1/C1812S105K1RACAUTO.pdf | Multilayer Ceramic Capacitors MLCC - SMD/SMT Multilayer Ceramic Capacitors MLCC - SMD/SMT 100V 1uF 10% X7R 1812 -55 / +125C AEC-Q200 | 80-C1812S105K1RAUTO | 8 | $0.76 | 1\1
C5,C8,C14,C26 | 0.1uF | Capacitor_SMD:C_0402_1005Metric | 4 | 81-GXT155R71E104KE1D | Murata | https://search.murata.co.jp/Ceramy/image/img/A01X/G101/ENG/GXT155R71E104KE01-01A.pdf | Multilayer Ceramic Capacitors MLCC - SMD/SMT Multilayer Ceramic Capacitors MLCC - SMD/SMT 0402 25VDC 0.1uF 10% X7R AEC-Q200 | 81-GXT155R71E104KE1D | 4 | $0.12 | 1\1 | $0.01 | $0.06
C7,C35,C40,C45,C46 | 10uF | Capacitor_SMD:C_0402_1005Metric | 5 | 81-GRM155C80G106ME8D | Murata | https://pim.murata.com/asset/pim4/ceramicCapacitorSMD/GRM155C80G106ME18-01A-EN_PDF_CERAMICCAPACITORSMD | Multilayer Ceramic Capacitors MLCC - SMD/SMT Multilayer Ceramic Capacitors MLCC - SMD/SMT 0402 4VDC 10uF 20% X6S | 81-GRM155C80G106ME8D | 5 | $0.33 | 1\1 | $0.04 | $0.21
C9 | .1uF | Capacitor_SMD:C_0402_1005Metric | 1 | 81-GXT155R71E104KE1D | Murata | https://search.murata.co.jp/Ceramy/image/img/A01X/G101/ENG/GXT155R71E104KE01-01A.pdf | Multilayer Ceramic Capacitors MLCC - SMD/SMT Multilayer Ceramic Capacitors MLCC - SMD/SMT 0402 25VDC 0.1uF 10% X7R AEC-Q200 | 81-GXT155R71E104KE1D | 1 | $0.12 | 1\1 | $0.01 | $0.02
C11 | 100uF | PCM_Capacitor_SMD_AKL:C_1206_3216Metric | 1 | 581-KGM31HR50J107MU | KYOCERA AVX | https://datasheets.kyocera-avx.com/cx5r-KGM.pdf | Multilayer Ceramic Capacitors MLCC - SMD/SMT Multilayer Ceramic Capacitors MLCC - SMD/SMT 6.3V 100uF X5R 1206 20% | 581-KGM31HR50J107MU | 1 | $0.99 | 1\1
C16,C17 | 22pF | Capacitor_SMD:C_0402_1005Metric | 2 | 581-KAM05ACG1H220FH | KYOCERA AVX | https://datasheets.kyocera-avx.com/AutoMLCCKAM.pdf | Multilayer Ceramic Capacitors MLCC - SMD/SMT Multilayer Ceramic Capacitors MLCC - SMD/SMT 50V 22pF C0G 0402 1% AEC-Q200 | 581-KAM05ACG1H220FH | 2 | $0.32 | 1\1 | $0.03 | $0.06
C27 | 3.9pF | Capacitor_SMD:C_0402_1005Metric | 1 | 77-VJ0402D3R9BXCAJ | Vishay | https://www.vishay.com/doc?45258 | Multilayer Ceramic Capacitors MLCC - SMD/SMT Multilayer Ceramic Capacitors MLCC - SMD/SMT 0402 3.9pF 200V C0G +/-.01pF HIFREQ | 77-VJ0402D3R9BXCAJ | 1 | $0.83 | 1\1
C39 | 2.2uF | Capacitor_SMD:C_0402_1005Metric | 1 | 81-GRM155Z71A225KE1J | Murata | https://www.mouser.com/datasheet/3/76/1/GRM155Z71A225KE01-01A.pdf | Multilayer Ceramic Capacitors MLCC - SMD/SMT Multilayer Ceramic Capacitors MLCC - SMD/SMT 2.2 uF 10 VDC 10% 0402 X7R | 81-GRM155Z71A225KE1J | 1 | $0.17 | 1\1 | $0.02 | $0.02
C41 | 3.3pF | Capacitor_SMD:C_0402_1005Metric | 1 | 77-VJ0402D3R3BXAAJHT | Vishay | https://www.vishay.com/doc?45239 | Multilayer Ceramic Capacitors MLCC - SMD/SMT Multilayer Ceramic Capacitors MLCC - SMD/SMT 0402 3.3pF 50V C0G .10pF HI FREQ | 77-VJ0402D3R3BXAAJHT | 1 | $0.78 | 1\1
C42,C43,C44,C48,C49 | 4.7uF | Capacitor_SMD:C_0402_1005Metric | 5 | 81-GRM15C61E475ME15J | Murata | https://www.mouser.com/datasheet/3/76/2/GRM155C61E475ME15_01A.pdf | Multilayer Ceramic Capacitors MLCC - SMD/SMT Multilayer Ceramic Capacitors MLCC - SMD/SMT 4.7 uF 25 VDC 20% 0402 X5S | 81-GRM15C61E475ME15J | 5 | $0.21 | 1\1 | $0.03 | $0.13
D1,D2 | LED | LED_SMD:LED_0402_1005Metric | 2 | 645-599-1A10-147F,720-Q65111A7377
D3 | MBR0530 | Diode_SMD:D_SOD-123 | 1 | 863-MBR0530T1G | onsemi | https://www.mouser.com/datasheet/3/101/1/043519E46271BA0592FB8B73F2596D6EB2077DBBAC974E694A9C922FE96E8957.pdf | Schottky Diodes & Rectifiers Schottky Diodes & Rectifiers 0.5A 30V | 863-MBR0530T1G | 1 | $0.14 | 1\1 | $0.02 | $0.02
D4 | TPD4E05U06DQAR | PCM_Package_SON_AKL:USON-10_2.5x1.0mm_P0.5mm | 1 | 595-TPD4E05U06DQAR | Texas Instruments | https://www.ti.com/lit/gpn/tpd6e05u06 | ESD Protection Diodes / TVS Diodes ESD Protection Diodes / TVS Diodes 4Chnl U-Lo Capacitnc IEC ESD Prot Diodes | 595-TPD4E05U06DQAR | 1 | $0.69 | 1\1 | $0.39 | $0.39
E1,H1,H2,H3,H4 | ~ | Connector_JST:JST_PH_S5B-PH-K_1x05_P2.00mm_Horizontal,ECE445L:MountingHole_4_40 | 5 | ~
J2 | Conn_02x05_Odd_Even | Connector_PinHeader_1.27mm:PinHeader_2x05_P1.27mm_Vertical_SMD | 1 | 485-4048 | Adafruit |  | Adafruit Accessories Adafruit Accessories Mini SWD 0.05 Pitch Connector - 10 Pin SMT Box Header | 485-4048 | 1 | $1.95 | 1\1
J3 | USB-C Connector | Connector_PinHeader_2.54mm:PinHeader_1x08_P2.54mm_Vertical | 1 | ~
L5 | 2.2uH | Inductor_SMD:L_0402_1005Metric_Pad0.77x0.64mm_HandSolder | 1 | 710-74404020033 | Wurth Elektronik | https://www.we-online.com/components/products/datasheet/74404020033.pdf | Power Inductors - SMD Power Inductors - SMD WE-LQS 3.3uH 870mA DCR=279mOhms AEC-Q200 | 710-74404020033 | 1 | $0.60 | 1\1 | $0.24 | $0.24
L7 | 6.8uH | Inductor_SMD:L_0402_1005Metric_Pad0.77x0.64mm_HandSolder | 1 | 710-74404020033 | Wurth Elektronik | https://www.we-online.com/components/products/datasheet/74404020033.pdf | Power Inductors - SMD Power Inductors - SMD WE-LQS 3.3uH 870mA DCR=279mOhms AEC-Q200 | 710-74404020033 | 1 | $0.60 | 1\1 | $0.24 | $0.24
R1,R2,R3,R4,R7,R8,R9,R10,R11,R13,R18 | 10K | Resistor_SMD:R_0402_1005Metric | 11 | 652-CR0402FX1002GPF,71-TNPW040210K9BEED
R5 | 1M | Resistor_SMD:R_0402_1005Metric | 1 | 594-MCS0402MD1004BE1 | Vishay | https://www.vishay.com/doc?28952 | Thin Film Resistors - SMD Thin Film Resistors - SMD MCS 0402-25 0.1% AT E1 1M0 | 594-MCS0402MD1004BE1 | 1 | $0.66 | 1\1 | $0.09 | $0.09
R12 | 1K | Resistor_SMD:R_0402_1005Metric | 1 | 279-CRG0402J1K0 | TE Connectivity | https://www.te.com/commerce/DocumentDelivery/DDEController?Action=srchrtrv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 | Thick Film Resistors - SMD Thick Film Resistors - SMD CRG0402 5% 1K0 | 279-CRG0402J1K0 | 1 | $0.10 | 1\1
R14 | 330 | Resistor_SMD:R_0402_1005Metric | 1 | 270-CRG0402J330R
R15 | 820 | Resistor_SMD:R_0402_1005Metric | 1 | 652-CR0402-JW-821GLF | Bourns | https://www.mouser.com/datasheet/3/40/1/cr.pdf | Thick Film Resistors - SMD Thick Film Resistors - SMD 820OHM 1/16WATT 5% | 652-CR0402-JW-821GLF | 1 | $0.10 | 1\1
R16,R19,R20 | 10k | Resistor_SMD:R_0402_1005Metric | 3 | 652-CR0402FX1002GPF | Bourns | https://www.mouser.com/datasheet/3/40/1/cr.pdf | Thick Film Resistors - SMD Thick Film Resistors - SMD Res 0402 10k 1% 63mW TC100 low lead | 652-CR0402FX1002GPF | 3 | $0.13 | 1\1
R17 | 250k | Resistor_SMD:R_0402_1005Metric | 1 | 708-RNCF0805BTE250K | SEI Stackpole | https://www.mouser.com/datasheet/3/1099/1/SEI-RNCF.pdf | Thin Film Resistors - SMD Thin Film Resistors - SMD 250Kohms 0805 25ppm 0.001 Precision AEC-Q200 | 708-RNCF0805BTE250K | 1 | $0.12 | 1\1 | $0.02 | $0.02
R21,R23 | 200K | Resistor_SMD:R_0402_1005Metric | 2 | 603-RP0805BRD07200KL | YAGEO | https://www.mouser.com/datasheet/3/508/1/PYU_RP_51_ROHS_L.pdf | Thin Film Resistors - SMD Thin Film Resistors - SMD 1/8 Wa 200K Ohm 0.1% 0805 AEC-Q200 | 603-RP0805BRD07200KL | 2 | $0.20 | 1\1 | $0.04 | $0.08
R22 | 499 | Resistor_SMD:R_0402_1005Metric | 1 | 708-RNAN0805BKE499R | SEI Stackpole | https://www.seielect.com/Catalog/SEI-rnan.PDF | Thin Film Resistors - SMD Thin Film Resistors - SMD 499Ohms 0805 25ppm Tol 0.1% High Power Alum Nitride | 708-RNAN0805BKE499R | 1 | $1.25 | 1\1 | $0.17 | $0.18
R24 | 698k | Resistor_SMD:R_0402_1005Metric | 1 | 71-TNPW1206698KBEEA | Vishay | https://www.vishay.com/doc?28758 | Thin Film Resistors - SMD Thin Film Resistors - SMD 698Kohms .1% 25ppm | 71-TNPW1206698KBEEA | 1 | $0.82 | 1\1 | $0.12 | $0.12
R25,R27 | 49.9K | Resistor_SMD:R_0402_1005Metric | 2 | 594-MCA12060D4992BP1 | Vishay | https://www.vishay.com/doc?28700 | Thin Film Resistors - SMD Thin Film Resistors - SMD 0.1W 49.9Kohm 0.1% 1206 25ppm Auto | 594-MCA12060D4992BP1 | 2 | $0.83 | 1\1
R26 | 453K | Resistor_SMD:R_0402_1005Metric | 1 | 279-RN73C1J453KBTD | TE Connectivity | https://www.mouser.com/datasheet/3/2640/1/ENG_DS_1773270_P1.pdf | Thin Film Resistors - SMD Thin Film Resistors - SMD RN 0603 453K 0.1% 10PPM 5K RL | 279-RN73C1J453KBTD | 1 | $0.68 | 1\1
SW1 | SW_Toggle | Connector_PinHeader_1.27mm:PinHeader_1x02_P1.27mm_Vertical | 1 | ~
TP1 | AVSS | TestPoint:TestPoint_Bridge_Pitch2.0mm_Drill0.7mm | 1 | ~
TP2 | AVDD | TestPoint:TestPoint_Bridge_Pitch2.0mm_Drill0.7mm | 1 | ~
TP3,TP4,TP5,TP6,TP7,TP8,TP9,TP10,TP11,TP12,TP14,TP15,TP16 | TP | TestPoint:TestPoint_THTPad_D1.0mm_Drill0.5mm | 13 | ~
U1 | ADS1299IPAG | ADS1299:PAG64_TEX | 1 | 595-ADS1299IPAG
U2 | TPD1E05U06DYA | Diode_SMD:D_SOD-523 | 1 | 595-TPD1E05U06DYAR | Texas Instruments | https://www.ti.com/lit/gpn/tpd6e05u06 | ESD Protection Diodes / TVS Diodes ESD Protection Diodes / TVS Diodes 0.5-pF 5.5-V &plus m n;12-kV ESD protect | 595-TPD1E05U06DYAR | 1 | $0.49 | 1\1 | $0.27 | $0.27
U3 | BNO086 | BNO080:IC_BNO080 | 1 | 526-BNO086 | CEVA | https://www.mouser.com/datasheet/3/5991/1/BNO080_085-Datasheet.pdf | IMUs - Inertial Measurement Units IMUs - Inertial Measurement Units 9-axis IMU | 526-BNO086 | 1 | $13.40 | 1\1
U4 | NPM1304-QEAA-R7 | Unknown:QFN-32-1EP_5x5mm_P0.5mm_EP3.6x3.6mm_ThermalVias_D3x3.00mm | 1 | 949-NPM1304-QEAA-R7 | Nordic Semiconductor |  | Power Management Specialized - PMIC Power Management Specialized - PMIC PMIC with battery charger 4-100mA, fuel gauge, 2x Buck, 2x LDO/LS, 5x GPIO, 3x LED drivers, TWI & system features | 949-NPM1304-QEAA-R7 | 1 | $1.53 | 1\1
U5 | LT3042xMSE | Package_SO:MSOP-10-1EP_3x3mm_P0.5mm_EP1.68x1.88mm | 1 | LT3042EMSE#TRPBF | Analog Devices Inc. | https://www.mouser.com/datasheet/3/1014/1/lt3042.pdf | LDO Voltage Regulators LDO Voltage Regulators 20V, 200mA, Ultralow N, Ultrahigh PSRR R | 584-LT3042EMSE#TRPBF | 1 | $9.24 | 1\1
U6 | TPS61040DBV | Package_TO_SOT_SMD:SOT-23-5 | 1 | 595-TPS61040DBVR | Texas Instruments | https://www.ti.com/lit/gpn/tps61041 | Switching Voltage Regulators Switching Voltage Regulators 28-V 400-mA Switch B oost Converter | 595-TPS61040DBVR | 1 | $1.25 | 1\1 | $0.70 | $0.70
U7 | BL54L15-453-000xxx | PCM_nordic-lib-kicad-nrf54-modules:BL54Lxx-LGA-39_14x10mm | 1 | 239-453-00001C | Ezurio | https://www.mouser.com/catalog/specsheets/EZURIO_12-09-2024_453-000-brief.pdf | Multiprotocol Modules Multiprotocol Modules Bluetooth Module, BL54L15, Bluetooth LE, Trace ANT, Cut Tape (Nordic nRF54L15) | 239-453-00001C | 1 | $4.25 | 1\1
Y1,Y2 | 32.768kHz | Crystal:Crystal_SMD_2012-2Pin_2.0x1.2mm,Crystal:Crystal_SMD_3215-2Pin_3.2x1.5mm | 2 | ABS06-32.768KHZ-7-T | ABRACON | https://www.mouser.com/datasheet/3/184/1/ABS06.pdf | Crystals Crystals 32.768 KHZ 7PF SMD | 815-ABS0632.768KHZ7T | 2 | $1.64 | 1\1
 |  |  | 1 | 645-599-1A10-147F | Dialight | https://www.mouser.com/datasheet/3/350/1/C18789.pdf | Single Color LEDs Single Color LEDs SMD 0402 0.35mm heightt Red | 645-599-1A10-147F | 1 | $0.23 | 1\1 | $0.04 | $0.04
 |  |  | 1 | 720-Q65111A7377 | ams OSRAM | https://www.mouser.com/datasheet/3/5912/1/LT_QH9G_EN.pdf | Single Color LEDs Single Color LEDs T GRN SMD LED CHIP LED 0402 | 720-Q65111A7377 | 1 | $0.45 | 1\1 | $0.07 | $0.07
 |  |  | 1 | 485-5804 | Adafruit |  | Ribbon Cables / IDC Cables Ribbon Cables / IDC Cables 10-pin 2x5 Socket-Socket 1.27mm IDC (SWD) Cable - 300mm long | 485-5804 | 1 | $3.50 | 1\1
 |  |  | 1 | 392-108464 | Soldered | https://www.mouser.com/catalog/specsheets/Soldered_108464 kapton tape 20mm width 10m.pdf | Adhesive Tapes Adhesive Tapes kapton, tape, 20mm, 10m | 392-108464 | 1 | $5.30 | 1\1 | $0.64 | $0.64
 |  |  | 1 | 595-ADS1299-4PAGR | Texas Instruments | https://www.ti.com/lit/gpn/ads1299-4 | Analog to Digital Converters - ADC Analog to Digital Converters - ADC Low-Noise 4-Channel 24-Bit Analog-to-D A A 595-ADS1299-4PAG | 595-ADS1299-4PAGR | 1 | $43.65 | 1\1

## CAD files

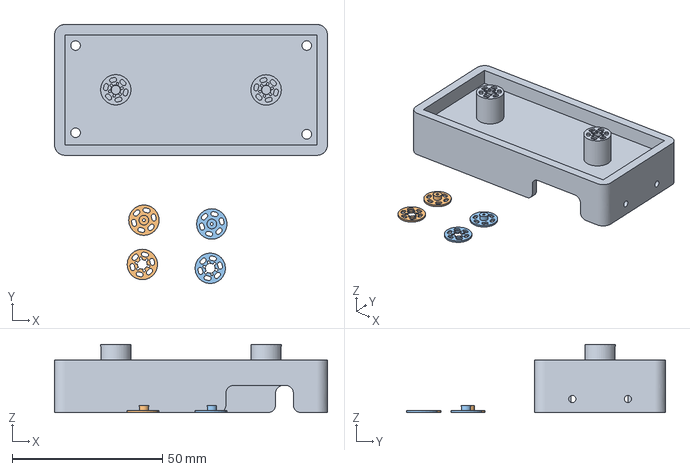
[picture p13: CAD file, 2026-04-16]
wearable/hw/cad/Button_Final.3mf
90.8 x 86.1 x 22.6 mm
Helmet_Model_Final.stl
Button_Final.stl x 2

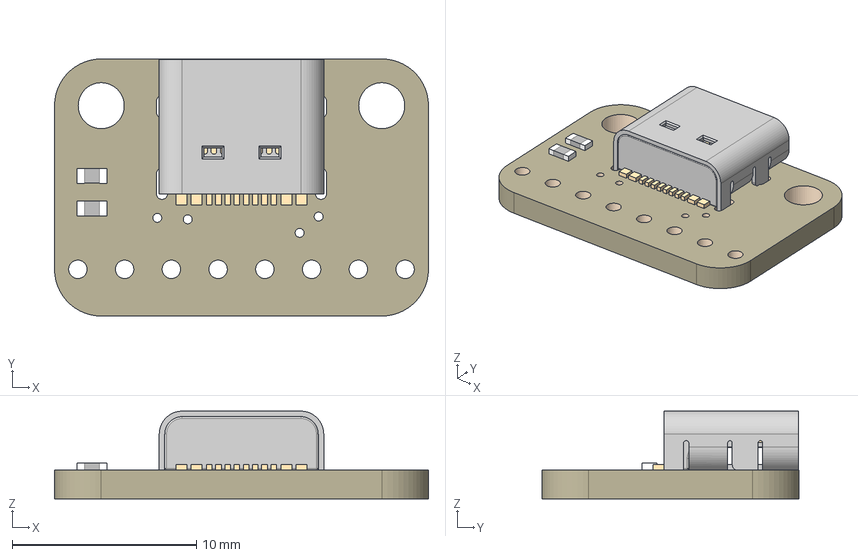
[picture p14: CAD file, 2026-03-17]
wearable/hw/wearable/assets/4090 USB C Breakout.step
20.3 x 14.0 x 4.77 mm
Board
USB_C_CUSB31-CFM2AX-01-X
5.1K x 2

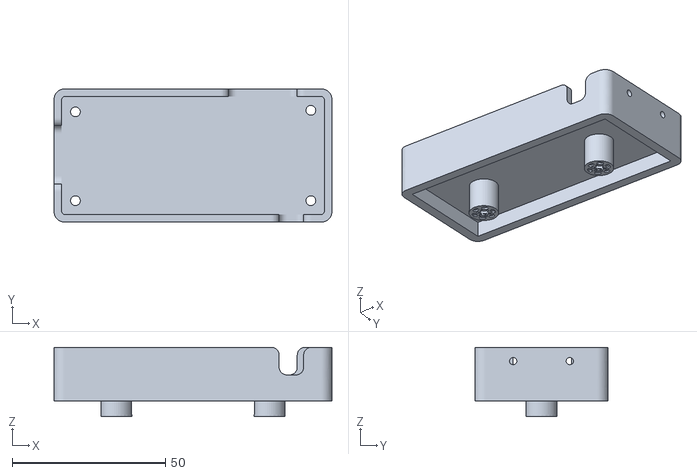
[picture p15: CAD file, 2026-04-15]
wearable/hw/cad/Helmet_Model_Final.stl
90.8 x 43.5 x 22.6

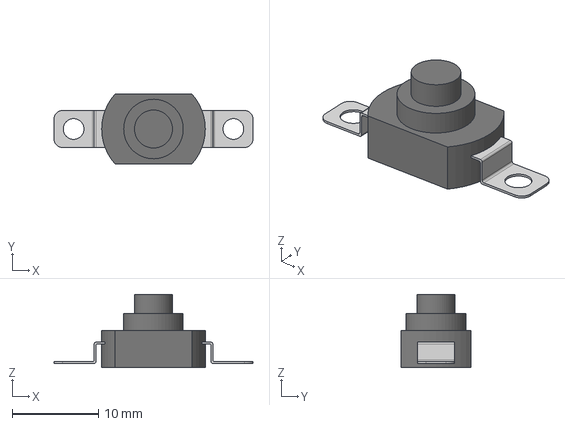
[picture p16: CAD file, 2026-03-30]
wearable/hw/cad/Adafruit_3870_button v1.step
23.0 x 8.10 x 8.50 mm

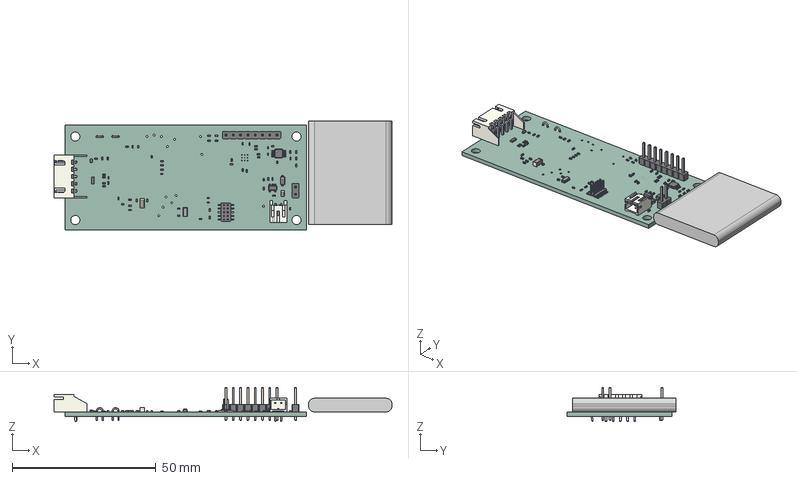
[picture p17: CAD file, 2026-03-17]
wearable/hw/cad/wearable.step
117.4 x 38.0 x 11.9 mm
R_0402_1005Metric x 26
TestPoint_Bridge_Pitch2.0mm_Drill0.7mm x 2
C_0402_1005Metric x 31
MSOP-10-1EP_3x3mm_P0.5mm_EP1.68x1.88mm
C_1206_3216Metric
L_0402_1005Metric
L_0805_2012Metric
Crystal_SMD_3215-2Pin_3.2x1.5mm
PinHeader_1x08_P2.54mm_Vertical
LED_0402_1005Metric x 2
SOT-23-5
USON-10_2.5x1.0mm_P0.5mm
D_SOD-123
D_SOD-523
JST_XH_S5B-XH-A-1_1x05_P2.50mm_Horizontal
PinHeader_1x02_P2.54mm_Vertical
PinHeader_2x05_P1.27mm_Vertical_SMD
JST_PH_S2B-PH-K_1x02_P2.00mm_Horizontal
1578 500mAh battery
wearable_PCB

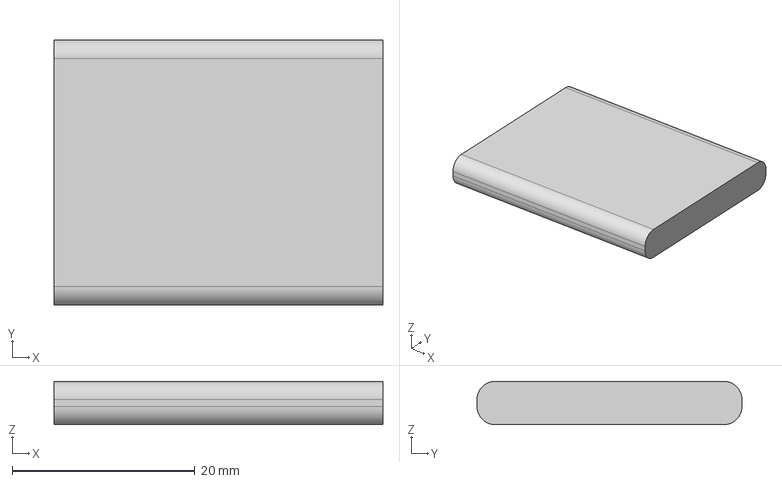
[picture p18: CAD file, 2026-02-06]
wearable/hw/cad/1578 500mAh battery.step
36.0 x 29.0 x 4.75 mm

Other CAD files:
wearable/hw/cad/Button_Final.stl

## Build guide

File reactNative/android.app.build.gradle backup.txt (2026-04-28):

apply plugin: "com.android.application"
apply plugin: "org.jetbrains.kotlin.android"
apply plugin: "com.facebook.react"

def projectRoot = rootDir.getAbsoluteFile().getParentFile().getAbsolutePath()

/**
 * This is the configuration block to customize your React Native Android app.
 * By default you don't need to apply any configuration, just uncomment the lines you need.
 */
react {
    entryFile = file(["node", "-e", "require('expo/scripts/resolveAppEntry')", projectRoot, "android", "absolute"].execute(null, rootDir).text.trim())
    reactNativeDir = new File(["node", "--print", "require.resolve('react-native/package.json')"].execute(null, rootDir).text.trim()).getParentFile().getAbsoluteFile()
    hermesCommand = new File(["node", "--print", "require.resolve('react-native/package.json')"].execute(null, rootDir).text.trim()).getParentFile().getAbsolutePath() + "/sdks/hermesc/%OS-BIN%/hermesc"
    codegenDir = new File(["node", "--print", "require.resolve('@react-native/codegen/package.json', { paths: [require.resolve('react-native/package.json')] })"].execute(null, rootDir).text.trim()).getParentFile().getAbsoluteFile()

    enableBundleCompression = (findProperty('android.enableBundleCompression') ?: false).toBoolean()
    // Use Expo CLI to bundle the app, this ensures the Metro config
    // works correctly with Expo projects.
    cliFile = new File(["node", "--print", "require.resolve('@expo/cli', { paths: [require.resolve('expo/package.json')] })"].execute(null, rootDir).text.trim())
    bundleCommand = "export:embed"

    /* Folders */
     //   The root of your project, i.e. where "package.json" lives. Default is '../..'
    // root = file("../../")
    //   The folder where the react-native NPM package is. Default is ../../node_modules/react-native
    // reactNativeDir = file("../../node_modules/react-native")
    //   The folder where the react-native Codegen package is. Default is ../../node_modules/@react-native/codegen
    // codegenDir = file("../../node_modules/@react-native/codegen")

    /* Variants */
    //   The list of variants to that are debuggable. For those we're going to
    //   skip the bundling of the JS bundle and the assets. By default is just 'debug'.
    //   If you add flavors like lite, prod, etc. you'll have to list your debuggableVariants.
    // debuggableVariants = ["liteDebug", "prodDebug"]

    /* Bundling */
    //   A list containing the node command and its flags. Default is just 'node'.
    // nodeExecutableAndArgs = ["node"]

    //
    //   The path to the CLI configuration file. Default is empty.
    // bundleConfig = file(../rn-cli.config.js)
    //
    //   The name of the generated asset file containing your JS bundle
    // bundleAssetName = "MyApplication.android.bundle"
    //
    //   The entry file for bundle generation. Default is 'index.android.js' or 'index.js'
    // entryFile = file("../js/MyApplication.android.js")
    //
    //   A list of extra flags to pass to the 'bundle' commands.
    //   See https://github.com/react-native-community/cli/blob/main/docs/commands.md#bundle
    // extraPackagerArgs = []

    /* Hermes Commands */
    //   The hermes compiler command to run. By default it is 'hermesc'
    // hermesCommand = "$rootDir/my-custom-hermesc/bin/hermesc"
    //
    //   The list of flags to pass to the Hermes compiler. By default is "-O", "-output-source-map"
    // hermesFlags = ["-O", "-output-source-map"]

    /* Autolinking */
    autolinkLibrariesWithApp()
}

/**
 * Set this to true in release builds to optimize the app using [R8](https://developer.android.com/topic/performance/app-optimization/enable-app-optimization).
 */
def enableMinifyInReleaseBuilds = (findProperty('android.enableMinifyInReleaseBuilds') ?: false).toBoolean()

/**
 * The preferred build flavor of JavaScriptCore (JSC)
 *
 * For example, to use the international variant, you can use:
 * `def jscFlavor = 'org.webkit:android-jsc-intl:+'`
 *
 * The international variant includes ICU i18n library and necessary data
 * allowing to use e.g. `Date.toLocaleString` and `String.localeCompare` that
 * give correct results when using with locales other than en-US. Note that
 * this variant is about 6MiB larger per architecture than default.
 */
def jscFlavor = 'io.github.react-native-community:jsc-android:2026004.+'

android {
    ndkVersion rootProject.ext.ndkVersion

    buildToolsVersion rootProject.ext.buildToolsVersion
    compileSdk rootProject.ext.compileSdkVersion

    namespace 'com.anonymous.Snoozy'
    defaultConfig {
        applicationId 'com.anonymous.Snoozy'
        minSdkVersion 29
        targetSdkVersion rootProject.ext.targetSdkVersion
        versionCode 1
        versionName "1.0.0"

        buildConfigField "String", "REACT_NATIVE_RELEASE_LEVEL", "\"${findProperty('reactNativeReleaseLevel') ?: 'stable'}\""
    }
    signingConfigs {
        debug {
            storeFile file('debug.keystore')
            storePassword 'android'
            keyAlias 'androiddebugkey'
            keyPassword 'android'
        }
    }
    buildTypes {
        debug {
            signingConfig signingConfigs.debug
        }
        release {
            // Caution! In production, you need to generate your own keystore file.
            // see https://reactnative.dev/docs/signed-apk-android.
            signingConfig signingConfigs.debug
            def enableShrinkResources = findProperty('android.enableShrinkResourcesInReleaseBuilds') ?: 'false'
            shrinkResources enableShrinkResources.toBoolean()
            minifyEnabled enableMinifyInReleaseBuilds
            proguardFiles getDefaultProguardFile("proguard-android.txt"), "proguard-rules.pro"
            def enablePngCrunchInRelease = findProperty('android.enablePngCrunchInReleaseBuilds') ?: 'true'
            crunchPngs enablePngCrunchInRelease.toBoolean()
        }
    }
    packagingOptions {
        jniLibs {
            def enableLegacyPackaging = findProperty('expo.useLegacyPackaging') ?: 'false'
            useLegacyPackaging enableLegacyPackaging.toBoolean()
        }
    }
    androidResources {
        ignoreAssetsPattern '!.svn:!.git:!.ds_store:!*.scc:!CVS:!thumbs.db:!picasa.ini:!*~'
    }
}

// Apply static values from `gradle.properties` to the `android.packagingOptions`
// Accepts values in comma delimited lists, example:
// android.packagingOptions.pickFirsts=/LICENSE,**/picasa.ini
["pickFirsts", "excludes", "merges", "doNotStrip"].each { prop ->
    // Split option: 'foo,bar' -> ['foo', 'bar']
    def options = (findProperty("android.packagingOptions.$prop") ?: "").split(",");
    // Trim all elements in place.
    for (i in 0..<options.size()) options[i] = options[i].trim();
    // `[] - ""` is essentially `[""].filter(Boolean)` removing all empty strings.
    options -= ""

    if (options.length > 0) {
        println "android.packagingOptions.$prop += $options ($options.length)"
        // Ex: android.packagingOptions.pickFirsts += '**/SCCS/**'
        options.each {
            android.packagingOptions[prop] += it
        }
    }
}

dependencies {
    // onnxruntime-react-native @generated begin onnxruntime-react-native - expo prebuild (DO NOT MODIFY) sync-ec94e2a0d49f04b1bbc51ec3f57c45710b04aad8
    implementation project(':onnxruntime-react-native')
    // onnxruntime-react-native @generated end onnxruntime-react-native
    // The version of react-native is set by the React Native Gradle Plugin
    implementation("com.facebook.react:react-android")

    def isGifEnabled = (findProperty('expo.gif.enabled') ?: "") == "true";
    def isWebpEnabled = (findProperty('expo.webp.enabled') ?: "") == "true";
    def isWebpAnimatedEnabled = (findProperty('expo.webp.animated') ?: "") == "true";

    if (isGifEnabled) {
        // For animated gif support
        implementation("com.facebook.fresco:animated-gif:${expoLibs.versions.fresco.get()}")
    }

    if (isWebpEnabled) {
        // For webp support
        implementation("com.facebook.fresco:webpsupport:${expoLibs.versions.fresco.get()}")
        if (isWebpAnimatedEnabled) {
            // Animated webp support
            implementation("com.facebook.fresco:animated-webp:${expoLibs.versions.fresco.get()}")
        }
    }

    if (hermesEnabled.toBoolean()) {
        implementation("com.facebook.react:hermes-android")
    } else {
        implementation jscFlavor
    }
}

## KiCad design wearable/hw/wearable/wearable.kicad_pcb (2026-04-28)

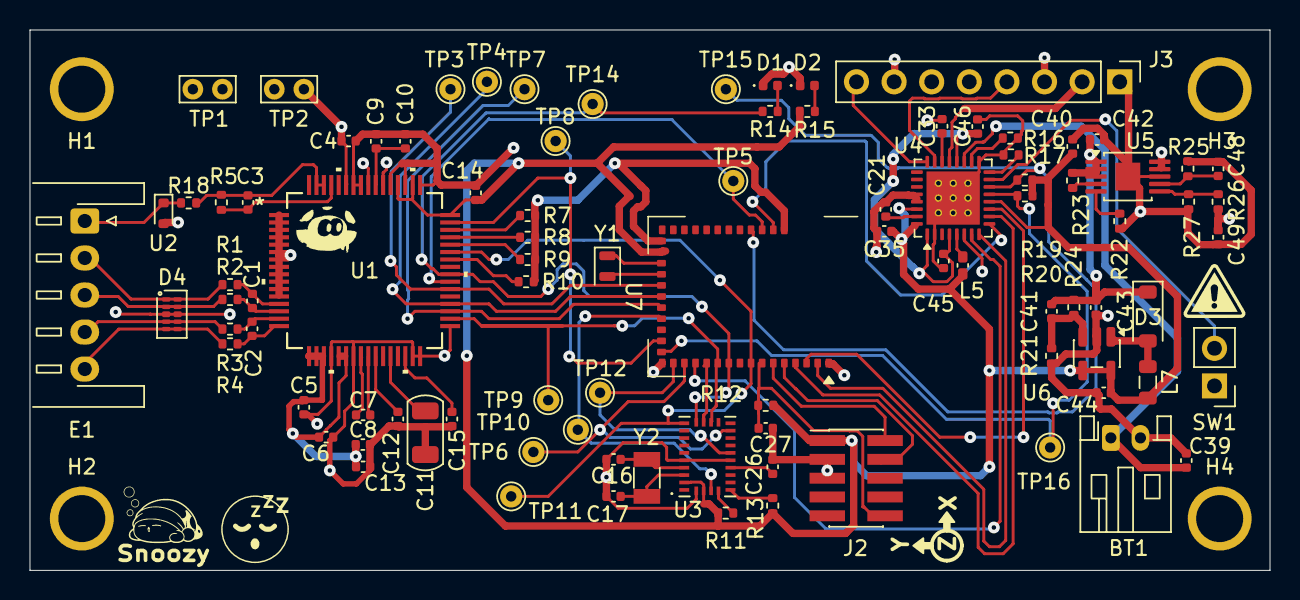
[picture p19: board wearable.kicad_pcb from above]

Board: 4 copper layers, 83.8 x 36.5 mm, 97 parts (0 on the bottom side), 73 nets.

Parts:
BT1: 3.7V; JST_PH_S2B-PH-K_1x02_P2.00mm_Horizontal
C1, C2: 4.7nF; C_0402_1005Metric
C3: 1.5nF; C_0402_1005Metric
C4, C6, C10, C12, C13, C15, C21, C33: 1uF; C_0402_1005Metric
C5, C8, C14, C26: 0.1uF; C_0402_1005Metric
C7, C35, C40, C45, C46: 10uF; C_0402_1005Metric
C9: .1uF; C_0402_1005Metric
C11: 100uF; C_1206_3216Metric
C16, C17: 22pF; C_0402_1005Metric
C27: 3.9pF; C_0402_1005Metric
C39: 2.2uF; C_0402_1005Metric
C41: 3.3pF; C_0402_1005Metric
C42, C43, C44, C48, C49: 4.7uF; C_0402_1005Metric
D1, D2: LED; LED_0402_1005Metric
D3: MBR0530; D_SOD-123
D4: TPD4E05U06DQAR; USON-10_2.5x1.0mm_P0.5mm
E1: JST_XH_S5B-XH-A-1_1x05_P2.50mm_Horizontal
H1, H2, H3, H4: MountingHole_4_40
J2: Conn_02x05_Odd_Even; PinHeader_2x05_P1.27mm_Vertical_SMD
J3: USB-C Connector; PinHeader_1x08_P2.54mm_Vertical
L5: 2.2uH; L_0402_1005Metric_Pad0.77x0.64mm_HandSolder
L7: 6.8uH; L_0805_2012Metric
R1, R2, R3, R4, R7, R8, R9, R10, R11, R13, R18: 10K; R_0402_1005Metric
R5: 1M; R_0402_1005Metric
R12: 1K; R_0402_1005Metric
R14: 330; R_0402_1005Metric
R15: 820; R_0402_1005Metric
R16, R19, R20: 10k; R_0402_1005Metric
R17: 330k; R_0402_1005Metric
R21, R23: 200K; R_0402_1005Metric
R22: 499; R_0402_1005Metric
R24: 698k; R_0402_1005Metric
R25, R27: 49.9K; R_0402_1005Metric
R26: 453K; R_0402_1005Metric
SW1: PWR_Toggle; PinHeader_1x02_P2.54mm_Vertical
TP1: AVSS; TestPoint_Bridge_Pitch2.0mm_Drill0.7mm
TP2: AVDD; TestPoint_Bridge_Pitch2.0mm_Drill0.7mm
TP3, TP4, TP5, TP6, TP7, TP8, TP9, TP10, TP11, TP12, TP14, TP15, TP16: TP; TestPoint_THTPad_D1.5mm_Drill0.7mm
U1: ADS1299-4PAGR; PAG64_TEX
U2: TPD1E05U06DYA; D_SOD-523
U3: BNO086; IC_BNO080
U4: NPM1304-QEAA-R7; QFN-32-1EP_5x5mm_P0.5mm_EP3.6x3.6mm_ThermalVias_D3x3.00mm
U5: LT3042xMSE; MSOP-10-1EP_3x3mm_P0.5mm_EP1.68x1.88mm
U6: TPS61040DBV; SOT-23-5
U7: BL54L15-453-000xxx; BL54Lxx-LGA-39_14x10mm
Y1: 32.768kHz; Crystal_SMD_2012-2Pin_2.0x1.2mm
Y2: 32.768kHz; Crystal_SMD_3215-2Pin_3.2x1.5mm

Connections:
+3V3: C14.1, C35.1, C40.2, C44.1, J2.1, L5.1, L7.1, R11.1, R12.1, R13.1, R15.2, R19.1, R20.1, U1.48 (DVDD), U1.50 (DVDD), U1.52 (CLKSEL), U3.3 (VDD), U3.28 (VDDIO), U4.12 (VDDIO), U4.30 (LSIN2/VINLDO2), U4.32 (VOUT2), U6.4 (EN), U6.5 (VIN), U7.26 (VDD)
+5V3: C41.1, C42.1, C43.1, D3.1 (K), R23.1, R24.1, U5.1 (IN), U5.2 (IN), U5.3 (EN/UV)
+5V_USB: J3.2, U4.21 (VBUS)
/CAP: C26.1, U3.9 (CAP)
/XIN: C17.1, U3.27 (XIN32), Y2.1
/XOUT: C16.1, U3.26 (XOUT32/CLKSEL1), Y2.2
AVDD: C4.2, C5.1, C6.1, C8.1, C13.1, C49.1, R26.1, TP2.1, U1.1 (IN8N), U1.2 (IN8P), U1.3 (IN7N), U1.4 (IN7P), U1.5 (IN6N), U1.6 (IN6P), U1.7 (IN5N), U1.8 (IN5P), U1.9 (IN4N), U1.10 (IN4P), U1.11 (IN3N), U1.12 (IN3P), U1.17 (SRB1), U1.18 (SRB2), U1.19 (AVDD), U1.21 (AVDD), U1.22 (AVDD), U1.54 (AVDD1), U1.56 (AVDD), U1.59 (AVDD), U5.9 (OUTS), U5.10 (OUT)
AVSS: BT1.2 (-), C4.1, C5.2, C6.2, C8.2, C9.2, C10.2, C11.2, C12.2, C13.2, C14.2, C15.1, C16.2, C17.2, C21.2, C26.2, C27.2, C33.2, C35.2, C39.2, C40.1, C42.2, C43.2, C44.2, C45.2, C46.2, C48.2, C49.2, D1.1 (K), D2.1 (K), D4.3 (GND_1), D4.8 (GND_2), J2.3, J2.5, J3.1, J3.3, J3.7, R7.2, R8.2, R9.2, R10.2, R16.2, R17.2, R21.2, R22.2, R25.2, R27.2, SW1.1, TP1.1, U1.20 (AVSS), U1.23 (AVSS), U1.31 (RESV1), U1.32 (AVSS), U1.33 (DGND), U1.49 (DGND), U1.51 (DGND), U1.53 (AVSS1), U1.57 (AVSS), U1.58 (AVSS), U2.2 (GND), U3.2 (GND), U3.10 (CLKSEL0), U3.25 (GNDIO), U4.2 (PVSS1), U4.6 (PVSS2), U4.17 (VSET1), U4.28 (LSIN1/VINLDO1), U4.29 (LSOUT1/VOUTLDO1), U4.33 (AVSS), U5.8 (GND), U5.11 (GND), U6.2 (GND), U7.1 (VSS), U7.16 (VSS), U7.27 (VSS), U7.39 (VSS)
BOOT_BNO085: TP10.1, U3.4 (~BOOT), U7.20 (P1.07)
CS_ADS1299: TP5.1, U1.39 (*CS), U7.37 (P2.10)
CS_BNO085: U3.18 (~H_CS), U7.12 (P2.05)
DRDY: TP8.1, U1.47 (*DRDY), U7.18 (P0.01)
GPIO0: U4.7 (GPIO0), U7.13 (P2.03)
GPIO1: U4.8 (GPIO1), U7.2 (P2.09)
GPIO2: U4.9 (GPIO2), U7.38 (P2.06)
GPIO3: U4.10 (GPIO3), U7.4 (P2.07)
GPIO4: U4.11 (GPIO4), U7.3 (P2.08)
INT_BNO085: TP6.1, U3.14 (~H_INT), U7.14 (P1.03)
MISO: TP11.1, U1.43 (DOUT), U3.20 (H_SDA/H_MISO/TX), U7.8 (P2.02)
MOSI: TP9.1, U1.34 (DIN), U3.17 (SA0/H_MOSI), U7.11 (P2.04)
unnamed: BT1.1 (+), C39.1, U4.19 (VBAT)
unnamed: D1.2 (A), R14.1
unnamed: D2.2 (A), R15.1
unnamed: D3.2 (A), L7.2, U6.1 (SW)
unnamed: D4.1 (D1+), D4.10 (NC_4), E1.2 (D1+), R1.2
unnamed: D4.2 (D1-), D4.9 (NC_3), E1.3 (D1-), R2.2
unnamed: D4.4 (D2+), D4.7 (NC_2), E1.4 (D2+), R3.2
unnamed: D4.5 (D2-), D4.6 (NC_1), E1.5 (D2-), R4.2
unnamed: J3.4, U4.23 (CC1)
unnamed: J3.8, U4.24 (CC2)
unnamed: C3.1, R5.1, R18.2, U1.62 (BIASIN), U1.63 (BIASOUT)
unnamed: C3.2, R5.2, U1.61 (BIASINV)
unnamed: R10.1, U1.42 (GPIO1)
unnamed: R9.1, U1.44 (GPIO2)
unnamed: R8.1, U1.45 (GPIO3)
unnamed: R7.1, U1.46 (GPIO4)
unnamed: C2.2, R3.1, U1.15 (IN1N)
unnamed: C2.1, R4.1, U1.16 (IN1P)
unnamed: C1.2, R1.1, U1.13 (IN2N)
unnamed: C1.1, R2.1, U1.14 (IN2P)
unnamed: C11.1, U1.28 (VCAP1)
unnamed: C15.2, U1.30 (VCAP2)
unnamed: C9.1, C10.1, U1.55 (VCAP3)
unnamed: C12.1, U1.26 (VCAP4)
unnamed: C7.2, U1.25 (VREFN)
unnamed: C7.1, U1.24 (VREFP)
unnamed: R13.2, U3.6 (PS0/WAKE)
unnamed: R11.2, U3.5 (PS1)
unnamed: C21.1, U4.31 (LSOUT2/VOUTLDO2)
unnamed: R16.1, U4.18 (NTC)
unnamed: SW1.2, U4.15 (SHPHLD)
unnamed: L5.2, U4.5 (SW2)
unnamed: C33.1, U4.22 (VBUSOUT)
unnamed: R17.1, U4.16 (VSET2)
unnamed: R22.1, U5.5 (ILIM)
unnamed: R23.2, U5.4 (PG)
unnamed: R26.2, R27.1, U5.6 (PGFB)
unnamed: C48.1, R25.1, U5.7 (SET)
unnamed: C41.2, R21.1, R24.2, U6.3 (FB)
unnamed: U7.25 (P1.00), Y1.1
unnamed: U7.24 (P1.01), Y1.2
PWDWN_ADS1299: TP7.1, U1.35 (*PWDN), U7.21 (P1.06)
RESET: C27.1, J2.10, R12.2, U7.7 (~RESET)
RST_ADS1299: TP4.1, U1.36 (*RESET), U7.22 (P1.05)
RST_BNO085: TP12.1, U3.11 (~RST), U7.15 (P1.02)
SCK: R14.2, TP14.1, U1.40 (SCLK), U3.19 (H_SCL/SCK/RX), U7.10 (P2.01)
SCL: R19.2, TP15.1, U4.14 (SCL), U7.36 (P0.03)
SDA: R20.2, TP16.1, U4.13 (SDA), U7.17 (P0.00)
START_ADS1299: TP3.1, U1.38 (START), U7.23 (P1.04)
SWDCLK: J2.4, U7.6 (SWDCLK)
SWDIO: J2.2, U7.5 (SWDIO)
VBIAS: E1.1 (Bias), R18.1, U2.1 (I/O)
VSYS: C45.1, C46.1, U4.1 (VOUT1), U4.4 (PVDD), U4.20 (VSYS)

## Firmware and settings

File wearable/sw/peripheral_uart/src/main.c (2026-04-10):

/*
 * Copyright (c) 2018 Nordic Semiconductor ASA
 *
 * SPDX-License-Identifier: LicenseRef-Nordic-5-Clause
 */

/** @file
 *  @brief Nordic UART Bridge Service (NUS) sample
 */
#include <uart_async_adapter.h>

#include <zephyr/types.h>
#include <zephyr/kernel.h>
#include <zephyr/drivers/uart.h>
#include <zephyr/usb/usb_device.h>

#include <zephyr/device.h>
#include <zephyr/devicetree.h>
#include <soc.h>

#include <zephyr/bluetooth/bluetooth.h>
#include <zephyr/bluetooth/uuid.h>
#include <zephyr/bluetooth/gatt.h>
#include <zephyr/bluetooth/hci.h>

#include <bluetooth/services/nus.h>

#include <zephyr/settings/settings.h>

#include <stdio.h>
#include <string.h>

#include <zephyr/logging/log.h>

#define LOG_MODULE_NAME peripheral_uart
LOG_MODULE_REGISTER(LOG_MODULE_NAME);

#define STACKSIZE CONFIG_BT_NUS_THREAD_STACK_SIZE
#define PRIORITY 7

#define DEVICE_NAME CONFIG_BT_DEVICE_NAME
#define DEVICE_NAME_LEN	(sizeof(DEVICE_NAME) - 1)

#define RUN_STATUS_LED DK_LED1
#define RUN_LED_BLINK_INTERVAL 1000

#define CON_STATUS_LED DK_LED2

#define KEY_PASSKEY_ACCEPT DK_BTN1_MSK
#define KEY_PASSKEY_REJECT DK_BTN2_MSK

#define UART_BUF_SIZE CONFIG_BT_NUS_UART_BUFFER_SIZE
#define UART_WAIT_FOR_BUF_DELAY K_MSEC(50)
#define UART_WAIT_FOR_RX CONFIG_BT_NUS_UART_RX_WAIT_TIME

static K_SEM_DEFINE(ble_init_ok, 0, 1);

static struct bt_conn *current_conn;
static struct bt_conn *auth_conn;
static struct k_work adv_work;

static const struct device *uart = DEVICE_DT_GET(DT_CHOSEN(nordic_nus_uart));
static struct k_work_delayable uart_work;

struct uart_data_t {
	void *fifo_reserved;
	uint8_t data[UART_BUF_SIZE];
	uint16_t len;
};

static K_FIFO_DEFINE(fifo_uart_tx_data);
static K_FIFO_DEFINE(fifo_uart_rx_data);

static const struct bt_data ad[] = {
	BT_DATA_BYTES(BT_DATA_FLAGS, (BT_LE_AD_GENERAL | BT_LE_AD_NO_BREDR)),
	BT_DATA(BT_DATA_NAME_COMPLETE, DEVICE_NAME, DEVICE_NAME_LEN),
};

static const struct bt_data sd[] = {
	BT_DATA_BYTES(BT_DATA_UUID128_ALL, BT_UUID_NUS_VAL),
};

#ifdef CONFIG_UART_ASYNC_ADAPTER
UART_ASYNC_ADAPTER_INST_DEFINE(async_adapter);
#else
#define async_adapter NULL
#endif

static void uart_cb(const struct device *dev, struct uart_event *evt, void *user_data)
{
	ARG_UNUSED(dev);

	static size_t aborted_len;
	struct uart_data_t *buf;
	static uint8_t *aborted_buf;
	static bool disable_req;

	switch (evt->type) {
	case UART_TX_DONE:
		LOG_DBG("UART_TX_DONE");
		if ((evt->data.tx.len == 0) ||
		    (!evt->data.tx.buf)) {
			return;
		}

		if (aborted_buf) {
			buf = CONTAINER_OF(aborted_buf, struct uart_data_t,
					   data[0]);
			aborted_buf = NULL;
			aborted_len = 0;
		} else {
			buf = CONTAINER_OF(evt->data.tx.buf, struct uart_data_t,
					   data[0]);
		}

		k_free(buf);

		buf = k_fifo_get(&fifo_uart_tx_data, K_NO_WAIT);
		if (!buf) {
			return;
		}

		if (uart_tx(uart, buf->data, buf->len, SYS_FOREVER_MS)) {
			LOG_WRN("Failed to send data over UART");
		}

		break;

	case UART_RX_RDY:
		LOG_DBG("UART_RX_RDY");
		buf = CONTAINER_OF(evt->data.rx.buf, struct uart_data_t, data[0]);
		buf->len += evt->data.rx.len;

		if (disable_req) {
			return;
		}

		if ((evt->data.rx.buf[buf->len - 1] == '\n') ||
		    (evt->data.rx.buf[buf->len - 1] == '\r')) {
			disable_req = true;
			uart_rx_disable(uart);
		}

		break;

	case UART_RX_DISABLED:
		LOG_DBG("UART_RX_DISABLED");
		disable_req = false;

		buf = k_malloc(sizeof(*buf));
		if (buf) {
			buf->len = 0;
		} else {
			LOG_WRN("Not able to allocate UART receive buffer");
			k_work_reschedule(&uart_work, UART_WAIT_FOR_BUF_DELAY);
			return;
		}

		uart_rx_enable(uart, buf->data, sizeof(buf->data),
			       UART_WAIT_FOR_RX);

		break;

	case UART_RX_BUF_REQUEST:
		LOG_DBG("UART_RX_BUF_REQUEST");
		buf = k_malloc(sizeof(*buf));
		if (buf) {
			buf->len = 0;
			uart_rx_buf_rsp(uart, buf->data, sizeof(buf->data));
		} else {
			LOG_WRN("Not able to allocate UART receive buffer");
		}

		break;

	case UART_RX_BUF_RELEASED:
		LOG_DBG("UART_RX_BUF_RELEASED");
		buf = CONTAINER_OF(evt->data.rx_buf.buf, struct uart_data_t,
				   data[0]);

		if (buf->len > 0) {
			k_fifo_put(&fifo_uart_rx_data, buf);
		} else {
			k_free(buf);
		}

		break;

	case UART_TX_ABORTED:
		LOG_DBG("UART_TX_ABORTED");
		if (!aborted_buf) {
			aborted_buf = (uint8_t *)evt->data.tx.buf;
		}

		aborted_len += evt->data.tx.len;
		buf = CONTAINER_OF((void *)aborted_buf, struct uart_data_t,
				   data);

		uart_tx(uart, &buf->data[aborted_len],
			buf->len - aborted_len, SYS_FOREVER_MS);

		break;

	default:
		break;
	}
}

static void uart_work_handler(struct k_work *item)
{
	struct uart_data_t *buf;

	buf = k_malloc(sizeof(*buf));
	if (buf) {
		buf->len = 0;
	} else {
		LOG_WRN("Not able to allocate UART receive buffer");
		k_work_reschedule(&uart_work, UART_WAIT_FOR_BUF_DELAY);
		return;
	}

	uart_rx_enable(uart, buf->data, sizeof(buf->data), UART_WAIT_FOR_RX);
}

static bool uart_test_async_api(const struct device *dev)
{
	const struct uart_driver_api *api =
			(const struct uart_driver_api *)dev->api;

	return (api->callback_set != NULL);
}

static int uart_init(void)
{
	int err;
	int pos;
	struct uart_data_t *rx;
	struct uart_data_t *tx;

	if (!device_is_ready(uart)) {
		return -ENODEV;
	}

	if (IS_ENABLED(CONFIG_USB_DEVICE_STACK)) {
		err = usb_enable(NULL);
		if (err && (err != -EALREADY)) {
			LOG_ERR("Failed to enable USB");
			return err;
		}
	}

	rx = k_malloc(sizeof(*rx));
	if (rx) {
		rx->len = 0;
	} else {
		return -ENOMEM;
	}

	k_work_init_delayable(&uart_work, uart_work_handler);


	if (IS_ENABLED(CONFIG_UART_ASYNC_ADAPTER) && !uart_test_async_api(uart)) {
		/* Implement API adapter */
		uart_async_adapter_init(async_adapter, uart);
		uart = async_adapter;
	}

	err = uart_callback_set(uart, uart_cb, NULL);
	if (err) {
		k_free(rx);
		LOG_ERR("Cannot initialize UART callback");
		return err;
	}

	if (IS_ENABLED(CONFIG_UART_LINE_CTRL)) {
		LOG_INF("Wait for DTR");
		while (true) {
			uint32_t dtr = 0;

			uart_line_ctrl_get(uart, UART_LINE_CTRL_DTR, &dtr);
			if (dtr) {
				break;
			}
			/* Give CPU resources to low priority threads. */
			k_sleep(K_MSEC(100));
		}
		LOG_INF("DTR set");
		err = uart_line_ctrl_set(uart, UART_LINE_CTRL_DCD, 1);
		if (err) {
			LOG_WRN("Failed to set DCD, ret code %d", err);
		}
		err = uart_line_ctrl_set(uart, UART_LINE_CTRL_DSR, 1);
		if (err) {
			LOG_WRN("Failed to set DSR, ret code %d", err);
		}
	}

	tx = k_malloc(sizeof(*tx));

	if (tx) {
		pos = snprintf(tx->data, sizeof(tx->data),
			       "Starting Nordic UART service sample\r\n");

		if ((pos < 0) || (pos >= sizeof(tx->data))) {
			k_free(rx);
			k_free(tx);
			LOG_ERR("snprintf returned %d", pos);
			return -ENOMEM;
		}

		tx->len = pos;
	} else {
		k_free(rx);
		return -ENOMEM;
	}

	err = uart_tx(uart, tx->data, tx->len, SYS_FOREVER_MS);
	if (err) {
		k_free(rx);
		k_free(tx);
		LOG_ERR("Cannot display welcome message (err: %d)", err);
		return err;
	}

	err = uart_rx_enable(uart, rx->data, sizeof(rx->data), UART_WAIT_FOR_RX);
	if (err) {
		LOG_ERR("Cannot enable uart reception (err: %d)", err);
		/* Free the rx buffer only because the tx buffer will be handled in the callback */
		k_free(rx);
	}

	return err;
}

static void adv_work_handler(struct k_work *work)
{
	int err = bt_le_adv_start(BT_LE_ADV_CONN_FAST_2, ad, ARRAY_SIZE(ad), sd, ARRAY_SIZE(sd));

	if (err) {
		LOG_ERR("Advertising failed to start (err %d)", err);
		return;
	}

	LOG_INF("Advertising successfully started");
}

static void advertising_start(void)
{
	k_work_submit(&adv_work);
}

static void connected(struct bt_conn *conn, uint8_t err)
{
	char addr[BT_ADDR_LE_STR_LEN];

	if (err) {
		LOG_ERR("Connection failed, err 0x%02x %s", err, bt_hci_err_to_str(err));
		return;
	}

	bt_addr_le_to_str(bt_conn_get_dst(conn), addr, sizeof(addr));
	LOG_INF("Connected %s", addr);

	current_conn = bt_conn_ref(conn);

	dk_set_led_on(CON_STATUS_LED);
}

static void disconnected(struct bt_conn *conn, uint8_t reason)
{
	char addr[BT_ADDR_LE_STR_LEN];

	bt_addr_le_to_str(bt_conn_get_dst(conn), addr, sizeof(addr));

	LOG_INF("Disconnected: %s, reason 0x%02x %s", addr, reason, bt_hci_err_to_str(reason));

	if (auth_conn) {
		bt_conn_unref(auth_conn);
		auth_conn = NULL;
	}

	if (current_conn) {
		bt_conn_unref(current_conn);
		current_conn = NULL;
		dk_set_led_off(CON_STATUS_LED);
	}
}

static void recycled_cb(void)
{
	LOG_INF("Connection object available from previous conn. Disconnect is complete!");
	advertising_start();
}

#ifdef CONFIG_BT_NUS_SECURITY_ENABLED
static void security_changed(struct bt_conn *conn, bt_security_t level,
			     enum bt_security_err err)
{
	char addr[BT_ADDR_LE_STR_LEN];

	bt_addr_le_to_str(bt_conn_get_dst(conn), addr, sizeof(addr));

	if (!err) {
		LOG_INF("Security changed: %s level %u", addr, level);
	} else {
		LOG_WRN("Security failed: %s level %u err %d %s", addr, level, err,
			bt_security_err_to_str(err));
	}
}
#endif

BT_CONN_CB_DEFINE(conn_callbacks) = {
	.connected        = connected,
	.disconnected     = disconnected,
	.recycled         = recycled_cb,
#ifdef CONFIG_BT_NUS_SECURITY_ENABLED
	.security_changed = security_changed,
#endif
};

#if defined(CONFIG_BT_NUS_SECURITY_ENABLED)
static void auth_passkey_display(struct bt_conn *conn, unsigned int passkey)
{
	char addr[BT_ADDR_LE_STR_LEN];

	bt_addr_le_to_str(bt_conn_get_dst(conn), addr, sizeof(addr));

	LOG_INF("Passkey for %s: %06u", addr, passkey);
}

static void auth_passkey_confirm(struct bt_conn *conn, unsigned int passkey)
{
	char addr[BT_ADDR_LE_STR_LEN];

	auth_conn = bt_conn_ref(conn);

	bt_addr_le_to_str(bt_conn_get_dst(conn), addr, sizeof(addr));

	LOG_INF("Passkey for %s: %06u", addr, passkey);

	if (IS_ENABLED(CONFIG_SOC_SERIES_NRF54HX) || IS_ENABLED(CONFIG_SOC_SERIES_NRF54LX)) {
		LOG_INF("Press Button 0 to confirm, Button 1 to reject.");
	} else {
		LOG_INF("Press Button 1 to confirm, Button 2 to reject.");
	}
}


static void auth_cancel(struct bt_conn *conn)
{
	char addr[BT_ADDR_LE_STR_LEN];

	bt_addr_le_to_str(bt_conn_get_dst(conn), addr, sizeof(addr));

	LOG_INF("Pairing cancelled: %s", addr);
}


static void pairing_complete(struct bt_conn *conn, bool bonded)
{
	char addr[BT_ADDR_LE_STR_LEN];

	bt_addr_le_to_str(bt_conn_get_dst(conn), addr, sizeof(addr));

	LOG_INF("Pairing completed: %s, bonded: %d", addr, bonded);
}


static void pairing_failed(struct bt_conn *conn, enum bt_security_err reason)
{
	char addr[BT_ADDR_LE_STR_LEN];

	bt_addr_le_to_str(bt_conn_get_dst(conn), addr, sizeof(addr));

	LOG_INF("Pairing failed conn: %s, reason %d %s", addr, reason,
		bt_security_err_to_str(reason));
}

static struct bt_conn_auth_cb conn_auth_callbacks = {
	.passkey_display = auth_passkey_display,
	.passkey_confirm = auth_passkey_confirm,
	.cancel = auth_cancel,
};

static struct bt_conn_auth_info_cb conn_auth_info_callbacks = {
	.pairing_complete = pairing_complete,
	.pairing_failed = pairing_failed
};
#else
static struct bt_conn_auth_cb conn_auth_callbacks;
static struct bt_conn_auth_info_cb conn_auth_info_callbacks;
#endif

static void bt_receive_cb(struct bt_conn *conn, const uint8_t *const data,
			  uint16_t len)
{
	int err;
	char addr[BT_ADDR_LE_STR_LEN] = {0};

	bt_addr_le_to_str(bt_conn_get_dst(conn), addr, ARRAY_SIZE(addr));

	LOG_INF("Received data from: %s", addr);

	for (uint16_t pos = 0; pos != len;) {
		struct uart_data_t *tx = k_malloc(sizeof(*tx));

		if (!tx) {
			LOG_WRN("Not able to allocate UART send data buffer");
			return;
		}

		/* Keep the last byte of TX buffer for potential LF char. */
		size_t tx_data_size = sizeof(tx->data) - 1;

		if ((len - pos) > tx_data_size) {
			tx->len = tx_data_size;
		} else {
			tx->len = (len - pos);
		}

		memcpy(tx->data, &data[pos], tx->len);

		pos += tx->len;

		/* Append the LF character when the CR character triggered
		 * transmission from the peer.
		 */
		if ((pos == len) && (data[len - 1] == '\r')) {
			tx->data[tx->len] = '\n';
			tx->len++;
		}

		err = uart_tx(uart, tx->data, tx->len, SYS_FOREVER_MS);
		if (err) {
			k_fifo_put(&fifo_uart_tx_data, tx);
		}
	}
}

static struct bt_nus_cb nus_cb = {
	.received = bt_receive_cb,
};

void error(void)
{
	dk_set_leds_state(DK_ALL_LEDS_MSK, DK_NO_LEDS_MSK);

	while (true) {
		/* Spin for ever */
		k_sleep(K_MSEC(1000));
	}
}

#ifdef CONFIG_BT_NUS_SECURITY_ENABLED
static void num_comp_reply(bool accept)
{
	if (accept) {
		bt_conn_auth_passkey_confirm(auth_conn);
		LOG_INF("Numeric Match, conn %p", (void *)auth_conn);
	} else {
		bt_conn_auth_cancel(auth_conn);
		LOG_INF("Numeric Reject, conn %p", (void *)auth_conn);
	}

	bt_conn_unref(auth_conn);
	auth_conn = NULL;
}

void button_changed(uint32_t button_state, uint32_t has_changed)
{
	uint32_t buttons = button_state & has_changed;

	if (auth_conn) {
		if (buttons & KEY_PASSKEY_ACCEPT) {
			num_comp_reply(true);
		}

		if (buttons & KEY_PASSKEY_REJECT) {
			num_comp_reply(false);
		}
	}
}
#endif /* CONFIG_BT_NUS_SECURITY_ENABLED */

static void configure_gpio(void)
{
	int err;

#ifdef CONFIG_BT_NUS_SECURITY_ENABLED
	err = dk_buttons_init(button_changed);
	if (err) {
		LOG_ERR("Cannot init buttons (err: %d)", err);
	}
#endif /* CONFIG_BT_NUS_SECURITY_ENABLED */

	err = dk_leds_init();
	if (err) {
		LOG_ERR("Cannot init LEDs (err: %d)", err);
	}
}

void send_sensor_data(void)
{
    if (!current_conn) {
        // Blink LED3 if no connection
        dk_set_led(DK_LED3, 1);
        k_sleep(K_MSEC(100));
        dk_set_led(DK_LED3, 0);
        return;
    }
    
    if (voltage_mv < 0) {
        LOG_ERR("Failed to read ADC");
        return;
    }

    char buffer[32];
    /* Format as X.XXX V (e.g., "2.345V") */
    snprintf(buffer, sizeof(buffer), "%d.%03dV\r\n", 
             voltage_mv / 1000, 
             voltage_mv % 1000);
    
    int err = bt_nus_send(NULL, buffer, strlen(buffer));
    
    if (err) {
        // Blink LED4 on error
        dk_set_led(DK_LED4, 1);
        k_sleep(K_MSEC(100));
        dk_set_led(DK_LED4, 0);
    } else {
        // Blink LED3 on success
        dk_set_led(DK_LED3, 1);
        k_sleep(K_MSEC(100));
        dk_set_led(DK_LED3, 0);
    }
}

int main(void)
{
	int blink_status = 0;
	int err = 0;

	configure_gpio();

	err = uart_init();
	if (err) {
		error();
	}

	if (IS_ENABLED(CONFIG_BT_NUS_SECURITY_ENABLED)) {
		err = bt_conn_auth_cb_register(&conn_auth_callbacks);
		if (err) {
			LOG_ERR("Failed to register authorization callbacks. (err: %d)", err);
			return 0;
		}

		err = bt_conn_auth_info_cb_register(&conn_auth_info_callbacks);
		if (err) {
			LOG_ERR("Failed to register authorization info callbacks. (err: %d)", err);
			return 0;
		}
	}

	err = bt_enable(NULL);
	if (err) {
		error();
	}

	LOG_INF("Bluetooth initialized");

	k_sem_give(&ble_init_ok);

	if (IS_ENABLED(CONFIG_SETTINGS)) {
		settings_load();
	}

	err = bt_nus_init(&nus_cb);
	if (err) {
		LOG_ERR("Failed to initialize UART service (err: %d)", err);
		return 0;
	}

	k_work_init(&adv_work, adv_work_handler);
	advertising_start();

	for (;;) {
		dk_set_led(RUN_STATUS_LED, (++blink_status) % 2);
		k_sleep(K_MSEC(RUN_LED_BLINK_INTERVAL));
	}
}

void ble_write_thread(void)
{
	/* Don't go any further until BLE is initialized */
	k_sem_take(&ble_init_ok, K_FOREVER);
	struct uart_data_t nus_data = {
		.len = 0,
	};

	for (;;) {
		/* Wait indefinitely for data to be sent over bluetooth */
		struct uart_data_t *buf = k_fifo_get(&fifo_uart_rx_data,
						     K_FOREVER);

		int plen = MIN(sizeof(nus_data.data) - nus_data.len, buf->len);
		int loc = 0;

		while (plen > 0) {
			memcpy(&nus_data.data[nus_data.len], &buf->data[loc], plen);
			nus_data.len += plen;
			loc += plen;

			if (nus_data.len >= sizeof(nus_data.data) ||
			   (nus_data.data[nus_data.len - 1] == '\n') ||
			   (nus_data.data[nus_data.len - 1] == '\r')) {
				if (bt_nus_send(NULL, nus_data.data, nus_data.len)) {
					LOG_WRN("Failed to send data over BLE connection");
				}
				nus_data.len = 0;
			}

			plen = MIN(sizeof(nus_data.data), buf->len - loc);
		}

		k_free(buf);
	}
}

void sensor_thread(void)
{
    /* Don't go any further until BLE is initialized */
    k_sem_take(&ble_init_ok, K_FOREVER);

    while (1) {
        send_sensor_data();
        k_sleep(K_SECONDS(1));
    }
}

K_THREAD_DEFINE(sensor_thread_id, STACKSIZE, sensor_thread, NULL, NULL,
        NULL, PRIORITY-1, 0, 0);

K_THREAD_DEFINE(ble_write_thread_id, STACKSIZE, ble_write_thread, NULL, NULL,
		NULL, PRIORITY, 0, 0);

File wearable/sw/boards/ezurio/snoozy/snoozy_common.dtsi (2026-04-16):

/*
 * Copyright (c) 2024 Nordic Semiconductor ASA
 * Copyright (c) 2025 Ezurio LLC
 *
 * SPDX-License-Identifier: Apache-2.0
 */

#include "snoozy_nrf54l_10_15-pinctrl.dtsi"

/ {
    aliases {
        ads1299 = &ads1299;
        bno086 = &bno086;
        npm1304 = &npm1304;
    };
};

&spi20 {
    status = "okay";
    cs-gpios =  <&gpio2 10 GPIO_ACTIVE_LOW>, // TODO: do these map to ads and bno respectively? 
                <&gpio2 5 GPIO_ACTIVE_LOW>;

    ads1299: ads1299@0 {
        compatible = "ti,ads1299";          /* custom binding you'll define */
        reg = <0>;                           /* index into cs-gpios */
        spi-max-frequency = <4000000>;       /* ADS1299 max 4 MHz */
        label = "ADS1299";
        start-gpios = <&gpio1 4 GPIO_ACTIVE_LOW>;
        rst-gpios = <&gpio1 5 GPIO_ACTIVE_LOW>;
        pwdwn-gpios = <&gpio1 6 GPIO_ACTIVE_LOW>;
        drdy-gpios = <&gpio0 1 GPIO_ACTIVE_LOW>;
    };

    bno086: bno086@1 {
        compatible = "ceva,bno086";          /* custom binding you'll define */
        reg = <1>;                           /* index into cs-gpios */
        spi-max-frequency = <3000000>;       /* BNO086 max 3 MHz */
        label = "BNO086";
        int-gpios = <&gpio1 3 GPIO_ACTIVE_LOW>;
        rst-gpios = <&gpio1 2 GPIO_ACTIVE_LOW>;
        boot-gpios = <&gpio1 7 GPIO_ACTIVE_LOW>;
    };
};
/delete-node/ &{/pin-controller/uart20_default/group1/};
/delete-node/ &{/pin-controller/uart20_default/group2/};

&i2c22 {
    status = "okay";    /* enable the I2C bus */
    pinctrl-0 = <&i2c22_default>;
    pinctrl-names = "default";
    npm1304: pmic@6b {
        label = "npm1304";
        gpio-controller;
        compatible = "nordic,npm1304";
        reg = <0x6b>;

        regulators {
            ldo2: LDO2 {
                regulator-init-microvolt = <3000000>;
                regulator-boot-on;
            };

            pvss2: PVSS2 {
                regulator-boot-on;
            };
        };
        #gpio-cells = <2>;
    };

    clock-frequency = <I2C_BITRATE_STANDARD>;
};

/ {
    zephyr,user {
        // pmic-gpios = <&pmic 0 0>; // TODO: if we need to use pmic gpio in app, instantiate them here.
        ads_reset_gpios = <&gpio1 5 GPIO_ACTIVE_LOW>;
        ads_start_gpios = <&gpio1 4 GPIO_ACTIVE_LOW>;
        ads_drdy_gpios  = <&gpio0 1 GPIO_ACTIVE_LOW>;  /* replace X with your DRDY pin */
        ads_pwdwn_gpios = <&gpio1 6 GPIO_ACTIVE_LOW>;
    };
};


&pinctrl {
    spi20_default: spi20_default {
        group1 {
            psels = <NRF_PSEL(SPIM_SCK, 2, 1)>,
                    <NRF_PSEL(SPIM_MISO, 2, 2)>,
                    <NRF_PSEL(SPIM_MOSI, 2, 4)>;
            nordic,drive-mode = <NRF_DRIVE_H0H1>;
            bias-disable;
        };
    };
    i2c22_default: i2c22_default {
        group1 {
            psels = <NRF_PSEL(TWIM_SCL, 0, 3)>, <NRF_PSEL(TWIM_SDA, 0, 0)>;
        };
    };
};

/* BLE things. May not work outside of NUS example. */

// &uart20 {
// 	current-speed = <115200>;
// 	pinctrl-0 = <&uart20_default>;
// 	pinctrl-1 = <&uart20_sleep>;
// 	pinctrl-names = "default", "sleep";
// };

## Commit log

2025-10-28 Changed to Nordic UART Service (NUS) example
2025-10-29 Added KiCAD project and modified SW starter code
    [400148.DRL, 400148.GBL, 400148.GBO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]
2025-10-29 Added symbols and stuff to library
    [400148.DRL, 400148.GBL, 400148.GBO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]
2025-10-30 Updated schematic with needed parts
    [wearable.kicad_sch]
2025-10-31 Added 445L footprints/symbols and changed some stuff
    [Adafruit_BNO08x.kicad_sch, wearable.kicad_sch]
2025-11-09 Add peripheral UART source code
2025-11-09 Ignore boards directories
2025-11-10 Deleted files
    [400148.DRL, 400148.GBL, 400148.GBO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]
2025-11-10 Fixed all the jank in build
    [main.c]
2025-11-17 SPI api include
2025-11-30 WIP final schematic
    [400148.DRL, 400148.GBL, 400148.GBO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]
2025-11-30 Done with M3 schematic
    [wearable.kicad_sch]
2025-12-01 Moved around some stuff
    [wearable.kicad_sch]
2025-12-18 HW v1 complete
    [wearable.kicad_sch]
2025-12-19 HW v1 passes ERC
    [wearable.kicad_sch]
2025-12-19 Starting footprint assignments
    [wearable.kicad_sch]
2025-12-27 Big stuff
    [wearable.kicad_pcb, wearable.kicad_sch]
2026-01-08 Added 54LDK build
    [BNO080.step, imu.kicad_pcb, imu.kicad_sch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]
2026-01-12 Started early version of layout
    [wearable.kicad_pcb, wearable.kicad_sch]
2026-01-12 Starting to layout nrf54L15
    [wearable.kicad_pcb, wearable.kicad_sch]
2026-01-13 Placed a bunch of stuff
    [wearable.kicad_pcb, wearable.kicad_sch]
2026-01-13 Getting there
    [wearable.kicad_pcb, wearable.kicad_sch]
2026-01-14 More layout progress and some fun stuff
    [wearable.kicad_pcb, wearable.kicad_sch]
2026-01-14 Some more changes
    [wearable.kicad_pcb, wearable.kicad_sch]
2026-01-14 Some stuff
    [wearable.kicad_pcb, wearable.kicad_sch]
2026-01-14 Ground pours and more routing
    [wearable.kicad_pcb]
2026-01-15 Significant layout progress
    NOTE: We will need to rework the power management portion of the schematic due to layout issues
    [wearable.kicad_pcb, wearable.kicad_sch]
2026-01-15 Schematic of new power setup done
    [wearable.kicad_pcb, wearable.kicad_sch]
2026-01-15 Slop layout for new power block
    [wearable.kicad_pcb, wearable.kicad_sch]
2026-01-17 Questioning life choices
    [wearable.kicad_pcb, wearable.kicad_sch]
2026-01-17 Finished routing (mostly) + better testpoints
    [wearable.kicad_pcb, wearable.kicad_sch]
2026-01-18 Ready for review
    [wearable.kicad_pcb, wearable.kicad_sch]
2026-01-22 BL54L15 added
    [wearable-B_Cu.gbr, wearable-B_Mask.gbr, wearable-B_Paste.gbr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]
2026-01-26 Ready for design review
    [wearable.kicad_pcb]
2026-01-28 Checking with Alex
    [wearable.kicad_pcb, wearable.kicad_sch]
2026-01-28 Almost done with design review...
    [wearable.kicad_pcb, wearable.kicad_sch]
2026-01-28 Design review DONE
    [wearable.kicad_sch]
2026-01-30 Layed out design review changes
    [wearable.kicad_pcb]
2026-02-01 Added BoM for M1 prototype
    [PrototypeBoM.xlsx]
2026-02-02 ESD protection, cyton reference, silkscreen update
    [OBCI_V4_C (Component Positions CSV).csv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]
2026-02-02 hole cad
    [54L15_Helmet_Hole.stl]
2026-02-02 Printout documents, reworked analog inputs
    [wearable.kicad_pcb, wearable.kicad_sch]
2026-02-03 Demo FW complete, PCB layout finalized (awaiting review from staff)
    [wearable.kicad_pcb, wearable.kicad_sch]
2026-02-03 Prototype schematic done, organize repo a bit
    [OBCI_V4_C (Component Positions CSV).csv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]
2026-02-03 Improved design guide
    [prototype.kicad_sch]
2026-02-06 Prepping for ordering everything
    [1578 500mAh battery.step, BoM.xlsx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]
2026-02-09 Unpatched cheap PCB glitch
    [aisler-4-layer-hd-drc.kicad_pcb, aisler-4-layer-hd-drc.kicad_sch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]
2026-02-09 Prep for JLC
    [wearable.kicad_pcb]
2026-02-11 Passes JLCPCB DRU file
    [wearable-B_Cu.gbr, wearable-B_Mask.gbr, wearable-B_Paste.gbr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]
2026-02-11 Board ordered
    [wearable-B_Cu.gbr, wearable-B_Mask.gbr, wearable-B_Paste.gbr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]
2026-02-18 pmic devicetree
2026-03-04 pcb step file for case cad
    [wearable.step]
2026-03-04 configured devicetree for imu and adc
2026-03-17 Forgot to apply stash
    [4090 USB C Breakout.step, BoM.xlsx, wearable.kicad_pcb]
2026-03-24 POC of ML
    [Actigraph.csv, Activity.csv, RR.csv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]
2026-03-25 Updated backups
    [wearable.kicad_pcb]
2026-03-30 Added toggle button model
    [Adafruit_3870_button v1.step]
2026-03-30 moved cad files
    [1578 500mAh battery.step, 4090 USB C Breakout.step, Adafruit_3870_button v1.step]
2026-04-01 Auto stash before merge of "main" and "origin/main"
    [wearable.kicad_sch]
2026-04-01 snoozy final helmet cad file
2026-04-10 Documented SWD connector pin mismatch
    [wearable.kicad_pcb, wearable.kicad_sch]
2026-04-10 Snoozy is a board now
2026-04-11 Improved snoozy board files
2026-04-12 meditation onnx created
    [400148.DRL, 400148.GBL, 400148.GBO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]
2026-04-13 Device tree update
2026-04-15 Helmet CAD files
    [Button_Final.stl, Helmet_Model_Final.stl]
2026-04-15 LaTeX WIP drawings, renders, and minor changes
    [4090 USB C Breakout.step, wearable.kicad_pcb]
2026-04-15 spi debug
2026-04-16 fused model v4
    [lopo_fold_metrics.csv]
2026-04-17 Confusion Matrix decent
    [lopo_fold_metrics.csv]
2026-04-18 Call me a machine the way I'm learning
    [Actigraph.csv, Activity.csv, RR.csv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]
2026-04-28 Cleaned up repo structure
    [lopo_fold_metrics.csv]
2026-04-28 More cleaning of repo structure
    [400148.DRL, 400148.GBL, 400148.GBO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]
